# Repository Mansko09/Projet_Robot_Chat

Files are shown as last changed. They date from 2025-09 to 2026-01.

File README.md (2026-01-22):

# Projet Robot Chat

**ESE – Projet de groupe**

## Introduction

Dans le cadre de la spécialité de 3e année ESE à l'ENSEA, ce projet a pour objectif la conception complète d’un **robot mobile autonome à deux roues motrices**, destiné à participer à un jeu de type **chat et souris** face aux robots des autres groupes. Ce projet a été réalisé par Florian, David, Danilo et Mantou.
Au-delà de l’aspect ludique, ce projet mobilise des compétences variées en **électronique**, **mécanique** et **logiciel embarqué temps réel**, avec des contraintes fortes de sécurité (anti-chute), de réactivité et de robustesse matérielle.

Le robot, nommé **Félix**, doit être capable de se déplacer de manière autonome, de détecter son environnement, de réagir à des événements physiques (vide, chocs) et d’adapter dynamiquement son comportement.

---

## Objectifs fonctionnels

Pour atteindre ce comportement, plusieurs fonctions clés doivent être mises en place :

1. **Déplacement**

   * Roues + moteurs
   * Drivers de moteurs (PWM via timers)
   * Encodeurs (lecture via timers)

2. **Anti-chute**

   * Détection des bords avec capteur **ToF** (I²C)

3. **Détection des adversaires**

   * Capteur **LIDAR** pour repérer d’autres robots

4. **Détection de collisions**

   * Échange de rôles lors d’un choc (capteur **accéléromètre**)

5. **Communication**

   * Liaison **Bluetooth** (STM32WB55CEU6)

6. **Alimentation**

   * Batterie et gestion d’énergie (7.2 V → régulateurs 5 V & 3.3 V)

---

## Composants principaux

* **Microcontrôleur** : STM32WB55CEU6 (ARM Cortex-M4, BLE intégré)
* **Quartz** : 32 MHz 
* **Connecteur SWD/STLink** : (Farnell : 3226055)
* **Moteurs** : DFRobot FIT0520 ou FIT0521
* **Alimentation** : Batterie NiMH 7.2 V 1.3 Ah (RS : 777-0377)

  * Régulateur 5 V : MP1475DJ-LF-P
  * Régulateur 3.3 V : BU33SD5WG-TR
* **Drivers moteurs** : ZXBM5210 (un par roue)
* **Capteurs** :

  * LIDAR YDLIDAR X2
  * Accéléromètre ADXL343BCCZ-RL
  * Capteur ToF anti-chute
  * Multiplexeur : TCA9548A
* **Connecteurs** : JST 2.54 mm
* **Interface utilisateur** :

  * LED rouge/verte
  * Boutons poussoirs Wurth 430182070816 (6×6 mm, H9.5 mm)
  * Interrupteur ON/OFF Wurth 472121020311

---

## Conception réalisée

1. **Électronique**

   * Schéma électrique et PCB personnalisé
   * Routage, fabrication et soudure des composants

2. **Mécanique**

   * Conception du châssis sur **Onshape**
   * Intégration du PCB, moteurs, capteurs et batterie

3. **Logiciel embarqué**

   * Contrôle moteurs et capteurs

## Avancement du projet

* [x] Choix des composants et architecture générale
* [x] Schéma et routage PCB
* [x] Impression 3D du robot
* [x] Développement logiciel de base
* [ ] Intégration LIDAR et logique “chat/souris”

## Architecture générale 



## Structure du Code



### 1. Cerveau et Communication

Nous avons retenu le microcontrôleur **STM32WB55CEU6**, un choix motivé par des considérations de performance, de modularité et de fiabilité.

- **Mobilité et pilotage des drivers**  
  Chaque moteur est commandé par un driver piloté en PWM. Le logiciel intègre une gestion avancée des rampes de vitesse avec des profils asymétriques : accélération progressive et freinage brutal. Cette approche permet de préserver les moteurs tout en assurant un arrêt d’urgence immédiat lors de la détection de vide.  
  Les modes de freinage exploitent le **BRAKE_MODE** (court-circuit des moteurs) via le pont en H afin de garantir une immobilisation quasi instantanée sur les bords de table.

- **Intelligence embarquée et navigation**  
  Grâce à l’odométrie différentielle et aux encodeurs, la position $(x, y)$ ainsi que l’orientation $(\theta)$ du robot sont calculées en temps réel, permettant une navigation autonome précise.

- **Architecture logicielle sous FreeRTOS**  
  Le logiciel est structuré autour de plusieurs tâches concurrentes :
  - **Task_TOF** : mise à jour de la variable `vide` toutes les 20 ms, indiquant l’identifiant du capteur ToF détectant un vide ;
  - **Task_Motor** : gestion de l’odométrie et application des signaux PWM toutes les 10 ms ;
  - **Task_Control** : tâche décisionnelle principale, exécutée toutes les 20 ms, implémentant une machine à états finis (FSM) pilotant le comportement global du robot.

  **Rôle détaillé de la Task_Control**  
  La tâche **Task_Control** agit comme le véritable « cerveau » du robot. Elle fonctionne de manière asynchrone par rapport à la commande des moteurs et s’appuie sur une **Machine à États Finis (FSM)** pour orchestrer les actions de Félix en fonction des événements extérieurs.

  1. **Gestion de l’état global (Start / Stop)**  
     Avant toute logique de déplacement, la tâche surveille le flag `AccData`, mis à jour par l’accéléromètre via une interruption matérielle.  
     Un choc détecté agit comme un interrupteur logiciel (*toggle*) :
     - passage à l’état **Inactif** : LED rouge allumée, moteurs coupés ;
     - passage à l’état **Actif** : LED verte allumée, lancement de la mission.

  2. **Séquençage des déplacements (FSM)**  
     Lorsque le robot est actif, il suit un cycle comportemental conçu pour la survie et l’exploration :
     - **MOVE_FWD (marche avant)** : état par défaut. La tâche surveille en continu le registre `vide`. Dès qu’une bordure est détectée par un capteur ToF, une transition immédiate vers l’état de freinage est imposée.
     - **MOVE_BRAKE (sécurité)** : état intermédiaire déclenchant un arrêt d’urgence, voire une brève impulsion inverse, afin de compenser l’inertie et empêcher le dépassement du bord.
     - **MOVE_BACKWARD & MOVE_TURN** : une fois le robot immobilisé, une manœuvre de dégagement est engagée. Celle-ci est temporisée par `timer_state` et permet au robot de reculer, de modifier son orientation, puis de revenir automatiquement à l’état **MOVE_FWD**.

- **Perception sensorielle anti-chute**  
  Quatre capteurs **ToF VL53L0X** surveillent en permanence les angles du robot afin de détecter la présence de vide.

- **Détection de choc**  
  L’accéléromètre **ADXL343** est configuré en mode *Single Tap*. Un choc mécanique déclenche une interruption matérielle (EXTI) provoquant l’arrêt immédiat du robot et l’allumage de la LED rouge. Un second choc relance le système et active la LED verte.

## Ce qui fonctionne

- Déplacement fluide à une vitesse donnée du robot
- Détection de vide par les capteurs **ToF**
- Détection de choc par l’**accéléromètre**
- Gestion des LED d’état
- Changement de comportement en fonction :
  - de la détection de vide ;
  - de la détection de choc (Start / Stop)
 
## Ce qui ne fonctionne pas / partiellement

- **Bluetooth** : dysfonctionnement lié à un problème de quartz, empêchant la communication BLE
- **LIDAR** : matériel fonctionnel, mais logique logicielle incomplète
- **Asservissement** : implémenté mais non testé

## Challenges techniques rencontrés

### 1. Routage du PCB
Le premier défi a été le routage de la carte électronique :
- placement optimal des composants dans un espace réduit ;
- maintien des condensateurs de découplage au plus près du microcontrôleur ;
- isolation stricte de l’antenne Bluetooth ;
- optimisation des plans de masse ;
- éviter toute structure pouvant agir comme une antenne parasite.

### 2. Programmation du comportement du robot
Coder le comportement de Félix a été un défi majeur, non pas par la complexité de chaque fonction, mais par la nécessité de synchroniser une **logique** avec des **contraintes physiques réelles**.

#### a. Gestion du temps réel (priorités FreeRTOS)
Le robot ne doit jamais tomber, même lorsqu’il exécute d’autres calculs.
- **Problème** : la lecture des ToF via I²C est lente, alors que les moteurs nécessitent des mises à jour très fréquentes.
- **Solution** : architecture préemptive avec une priorité plus élevée pour la tâche ToF. En cas de détection de bord, elle interrompt la logique de contrôle pour forcer l’arrêt immédiat.

#### b. Passage du “tout ou rien” aux rampes (inertie)
- **Problème** : arrêts trop brutaux/lents provoquant des contraintes mécaniques (robot trop lourd à l'avant) ou un arrêt avec une roue en dehors de la table.
- **Solution** : implémentation de rampes asymétriques dans `Motor_UpdateSpeed` :
  - accélération douce (100 unités) ;
  - freinage très rapide (1000 unités).

Ce compromis entre protection mécanique et réactivité a nécessité de nombreux réglages.

#### c. Machine à États
- **Problème** : risque de blocage dans des situations critiques (coin de table, détections multiples).
- **Solution** : FSM rigoureuse avec des conditions de sortie strictes pour chaque état  
  (MOVE_FWD, MOVE_BRAKE, MOVE_BACKWARD, MOVE_TURN), garantissant un comportement déterministe et robuste.

https://github.com/user-attachments/assets/55dbaec2-2ef9-4583-8b24-4435a5f01540

## Conclusion

Ce projet a permis de mettre en pratique l’ensemble de la chaîne de conception d’un système embarqué autonome, depuis le routage d’un PCB jusqu’à la programmation temps réel sous FreeRTOS.  
Malgré certaines fonctionnalités incomplètes (Bluetooth, LIDAR), le robot démontre un comportement fiable et sécurisé face aux événements critiques. Les défis rencontrés ont été formateurs et ont mis en évidence l’importance de l’architecture logicielle et des choix matériels en amont dans un système embarqué réel.

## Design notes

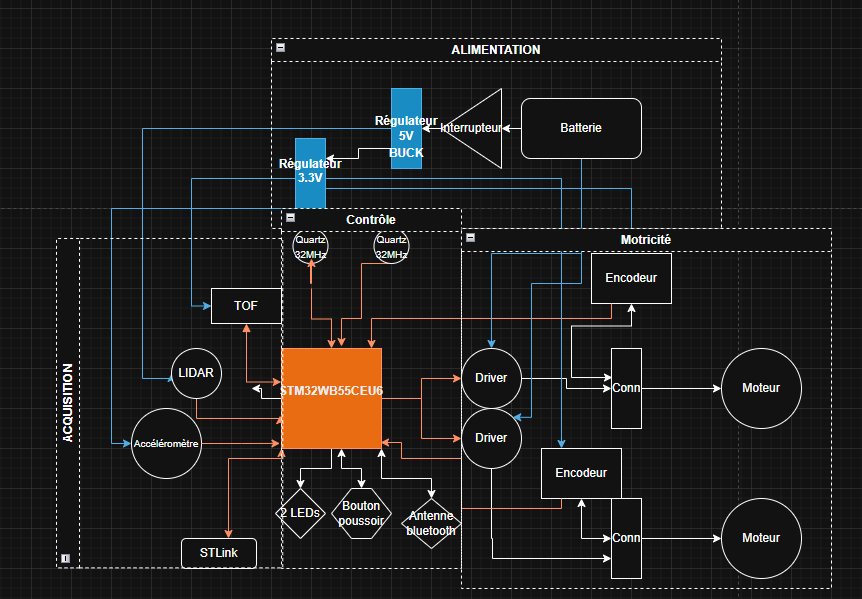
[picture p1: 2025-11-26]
Screenshots/Architecture_generale_Robot_Chat.png

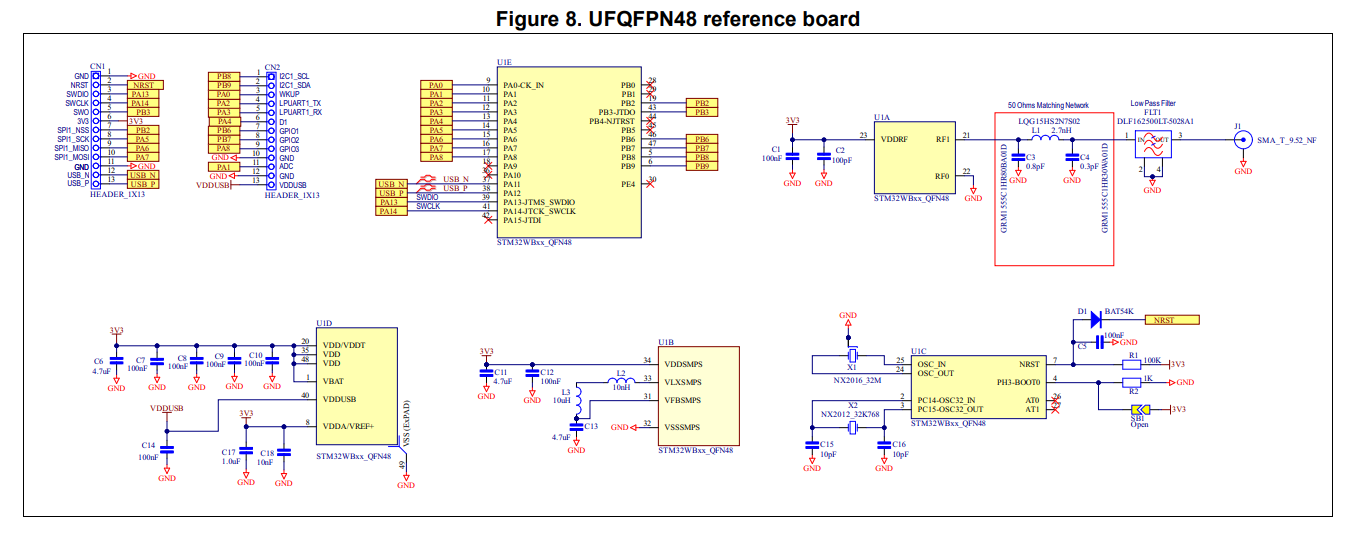
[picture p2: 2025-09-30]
Hardware/ROBOT-CHAT_PCB/Schematic_PCB/Capture d'écran 2025-09-11 083949.png

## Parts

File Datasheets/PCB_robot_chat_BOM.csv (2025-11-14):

Reference | Qty | Value | DNP | Exclude from BOM | Exclude from Board | Footprint | Datasheet
BU33SD5WG-TR1 | 1 | ~ |  |  |  | Package_TO_SOT_SMD:SOT-23-5
C1,C2,C11,C25,C27,C29 | 6 | 1uF |  |  |  | Capacitor_SMD:C_0603_1608Metric | ~
C3,C9,C15,C16 | 4 | 4.7uF |  |  |  | Capacitor_SMD:C_0603_1608Metric | ~
C4,C5,C6,C7,C8,C10,C13,C19,C20,C26,C28,C30 | 12 | 100n |  |  |  | Capacitor_SMD:C_0402_1005Metric | ~
C12 | 1 | 10nF |  |  |  | Capacitor_SMD:C_0402_1005Metric | ~
C14 | 1 | 100pF |  |  |  | Capacitor_SMD:C_0402_1005Metric | ~
C17,C18 | 2 | 10pF |  |  |  | Capacitor_SMD:C_0402_1005Metric | ~
C21 | 1 | 0.8pF |  |  |  | Capacitor_SMD:C_0402_1005Metric | ~
C22 | 1 | 22uF |  |  |  | Capacitor_SMD:C_0805_2012Metric | ~
C23,C301 | 2 | 22u |  |  |  | Capacitor_SMD:C_0805_2012Metric | ~
C24 | 1 | 0.3pF |  |  |  | Capacitor_SMD:C_0402_1005Metric | ~
D1 | 1 | LED |  |  |  | LED_SMD:LED_0603_1608Metric | ~
H101,H102,H103,H104 | 4 | MountingHole_Pad |  | Exclure de la Liste du Matériel |  | MountingHole:MountingHole_2.5mm_Pad_Via | ~
J1 | 1 | Conn_01x04 |  |  |  | Connector_JST:JST_XH_B4B-XH-AM_1x04_P2.50mm_Vertical | ~
J3,J4,J5,J6 | 4 | Conn_01x02 |  |  |  | Connector_JST:JST_PH_B2B-PH-K_1x02_P2.00mm_Vertical | ~
J7,J8 | 2 | Conn_01x06 |  |  |  | Connector_JST:JST_PH_B6B-PH-K_1x06_P2.00mm_Vertical | ~
J201 | 1 | Conn_ST_STDC14 |  |  |  | Connector_PinHeader_1.27mm:PinHeader_2x07_P1.27mm_Vertical_SMD | https://www.st.com/content/ccc/resource/technical/document/user_manual/group1/99/49/91/b6/b2/3a/46/e5/DM00526767/files/DM00526767.pdf/jcr:content/translations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
J501,J502,J503,J504 | 4 | Conn_01x04 |  |  |  | Connector_JST:JST_PH_B4B-PH-K_1x04_P2.00mm_Vertical | ~
L1 | 1 | 10nH |  |  |  | Inductor_SMD:L_0603_1608Metric | ~
L2 | 1 | 10uH |  |  |  | Inductor_SMD:L_0603_1608Metric | ~
L3 | 1 | 4.7uH |  |  |  | Bobine_74404054068:Bobine_74404054068 | ~
L4 | 1 | 2.7nH |  |  |  | Inductor_SMD:L_0603_1608Metric | ~
MP1475DJ-LF-P1 | 1 | ~ |  |  |  | Package_TO_SOT_SMD:TSOT-23-8
R1 | 1 | 16k |  |  |  | Resistor_SMD:R_0402_1005Metric | ~
R2 | 1 | 13k |  |  |  | Resistor_SMD:R_0402_1005Metric | ~
R3,R10 | 2 | 4.7k |  |  |  | Resistor_SMD:R_0402_1005Metric | ~
R4,R5,R6 | 3 | 1k |  |  |  | Resistor_SMD:R_0402_1005Metric | ~
R7,R301 | 2 | 100k |  |  |  | Resistor_SMD:R_0402_1005Metric | ~
R8 | 1 | 20 |  |  |  | Resistor_SMD:R_0402_1005Metric | ~
R9 | 1 | 40.2k |  |  |  | Resistor_SMD:R_0402_1005Metric | ~
R11,R12,R13,R14,R15,R16,R17,R18,R19,R20,R21 | 11 | 2k2 |  |  |  | Resistor_SMD:R_0402_1005Metric | ~
SW1 | 1 | SW_Push_Dual |  |  |  | SW_Push_1P1T_NO_6x6mm_H9.5mm:SW_Push_1P1T_NO_6x6mm_H9.5mm | ~
TP7,TP8,TP9,TP10,TP701,TP702,TP703,TP704 | 8 | TestPoint |  |  |  | TestPoint:TestPoint_Pad_D1.5mm | ~
U1 | 1 | STM32WB55CEUx |  |  |  | Package_DFN_QFN:QFN-48-1EP_7x7mm_P0.5mm_EP5.6x5.6mm | https://www.st.com/resource/en/datasheet/stm32wb55ce.pdf
U2 | 1 | TCA9546AD |  |  |  | Package_SO:SOIC-16_3.9x9.9mm_P1.27mm | https://www.ti.com/lit/ds/symlink/tca9546a.pdf
U4 | 1 | ADXL343 |  |  |  | Package_LGA:LGA-14_3x5mm_P0.8mm_LayoutBorder1x6y | https://www.analog.com/media/en/technical-documentation/data-sheets/ADXL343.pdf
U5,U6 | 2 | ZXBM5210-SP |  |  |  | Package_SO:Diodes_SO-8EP | https://www.diodes.com/assets/Datasheets/ZXBM5210.pdf
U7 | 1 | ~ |  |  |  | AMCA31-2R450G-S1F-T3:AMCA31-2R450G-S1F-T3
U8 | 1 | ~ |  |  |  | LowPass:LOWPASS
Y2 | 1 | 32MHz |  |  |  | XRCGB32M000F2P01R0:XRCGB32M000F2P01R0 | ~
Y201 | 1 | Crystal_Small |  |  |  | ABS07AIG-32.768KHZ-6-D-T:ABS07AIG-32.768KHZ-6-D-T | ~

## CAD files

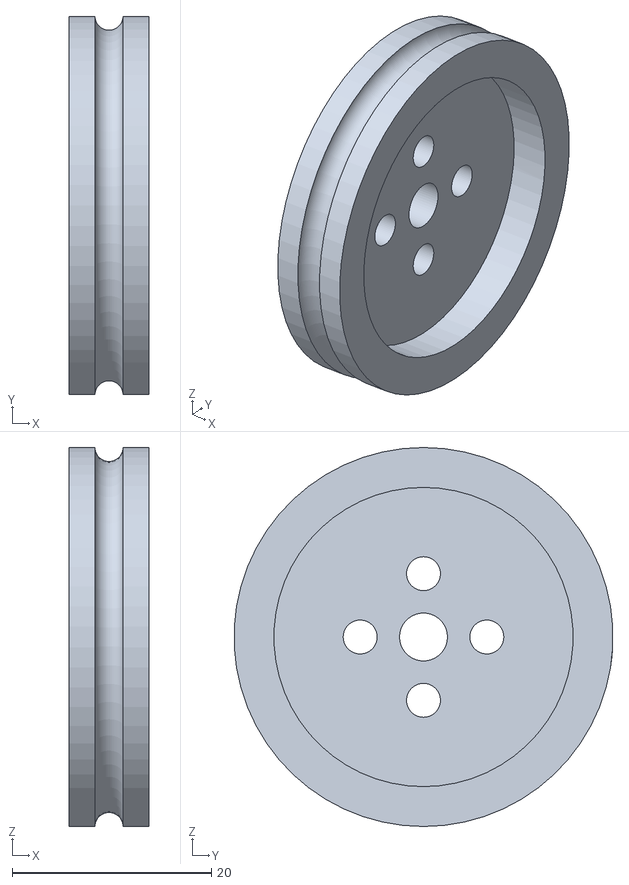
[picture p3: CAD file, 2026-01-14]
Meca/Wheels Clean V2.stl
8.00 x 37.9 x 38.0

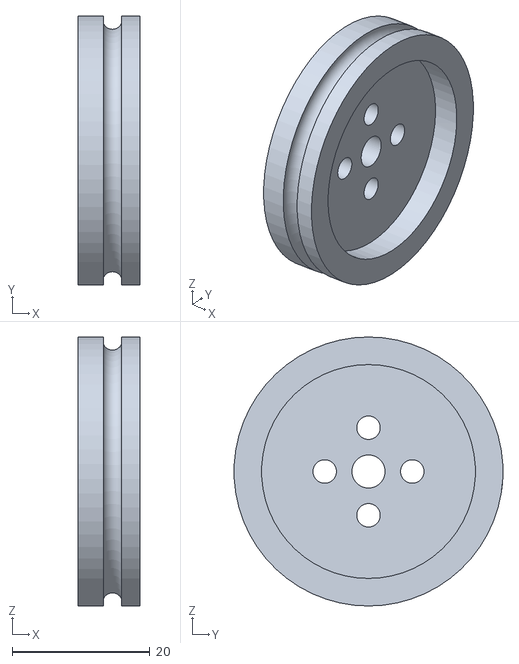
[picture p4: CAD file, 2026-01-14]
Meca/Wheels_Clean_V4.stl
9.00 x 38.9 x 39.0

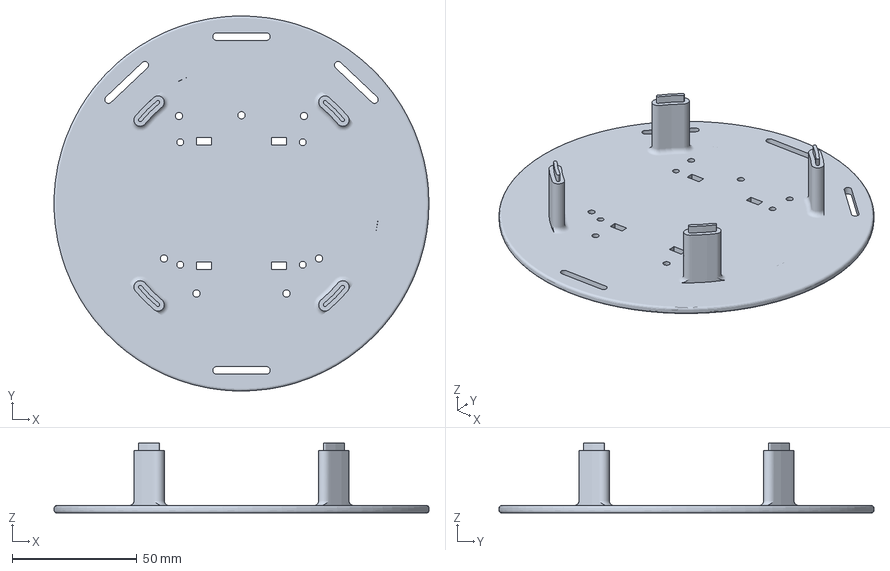
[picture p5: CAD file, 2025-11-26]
Meca/Tower - TOF.3mf
150.0 x 150.0 x 28.0 mm

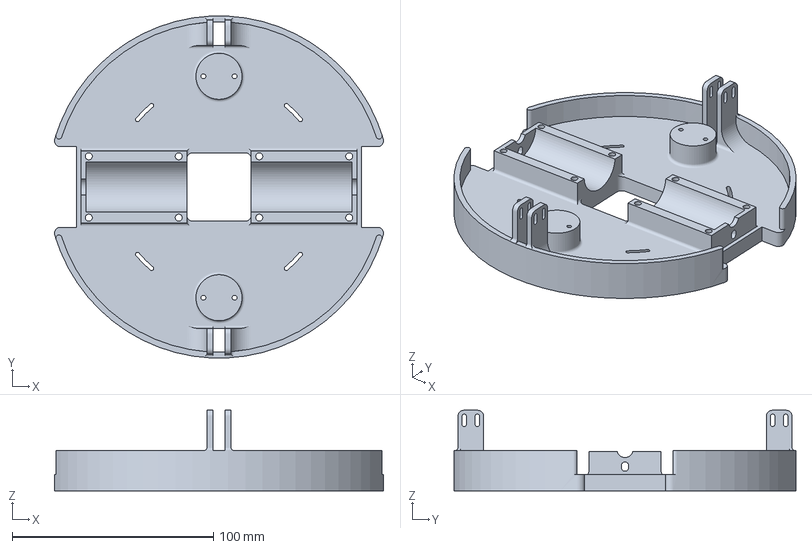
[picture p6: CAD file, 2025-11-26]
Meca/Base - Parts.3mf
163.4 x 169.8 x 40.0 mm

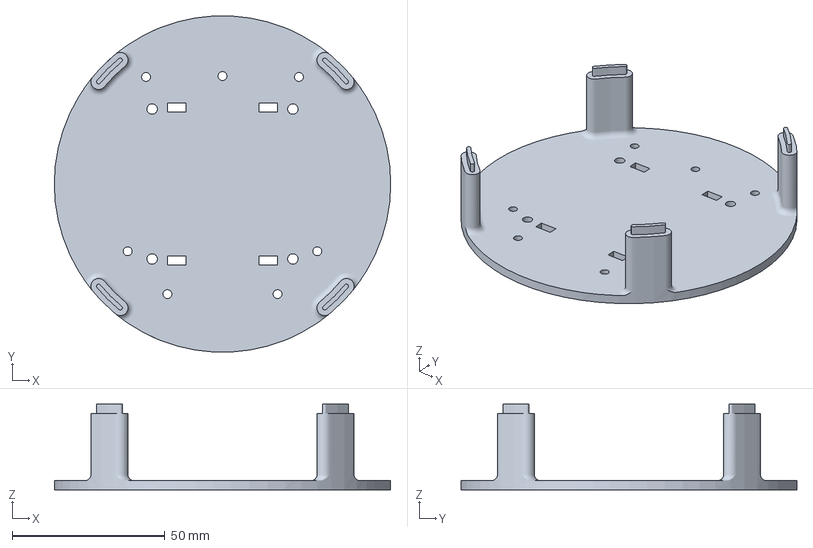
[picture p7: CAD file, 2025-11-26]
Meca/Tower - Parts.3mf
110.0 x 109.8 x 28.0 mm

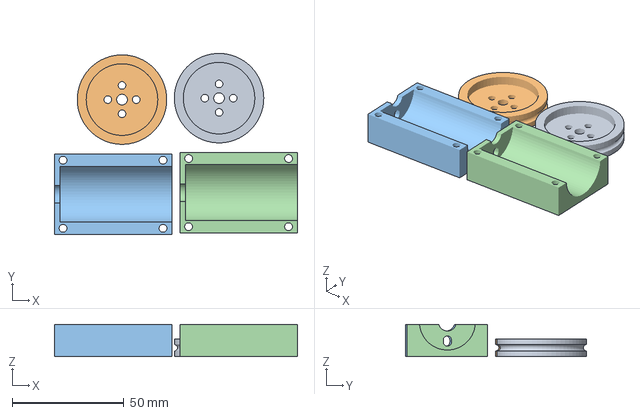
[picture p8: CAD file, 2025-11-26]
Meca/Wheels Clean.3mf
108.6 x 80.9 x 14.5 mm
Wheels Clean.stl x 2
Base - Parts - Support Motor.stl x 2

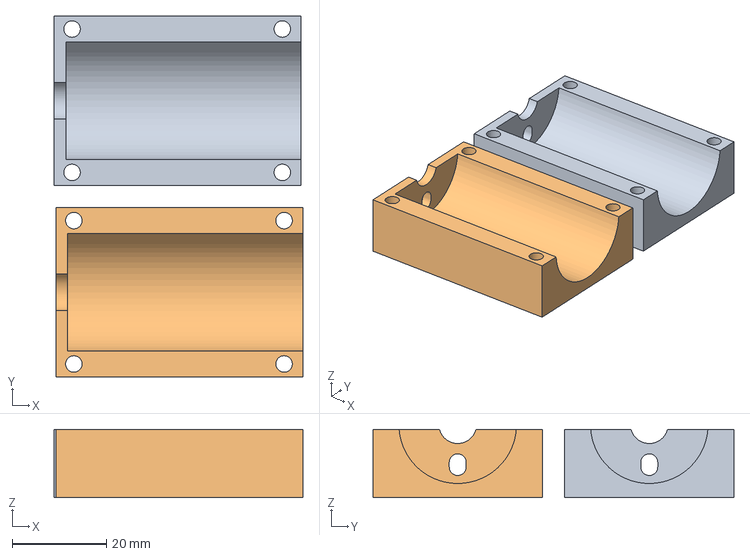
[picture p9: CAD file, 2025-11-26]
Meca/Base - Parts - Support Motor.3mf
52.9 x 76.7 x 14.5 mm
Base - Parts - Support Motor.stl x 2

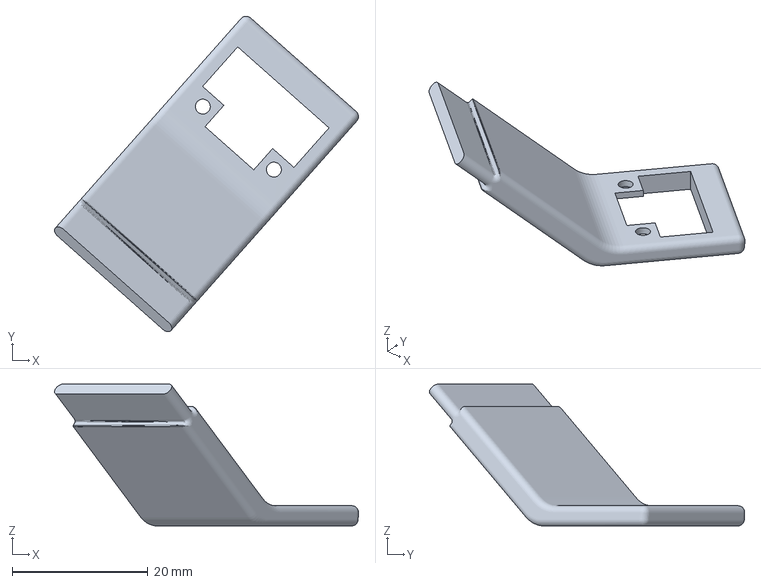
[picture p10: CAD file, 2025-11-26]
Meca/TOF.3mf
44.8 x 46.5 x 20.9 mm

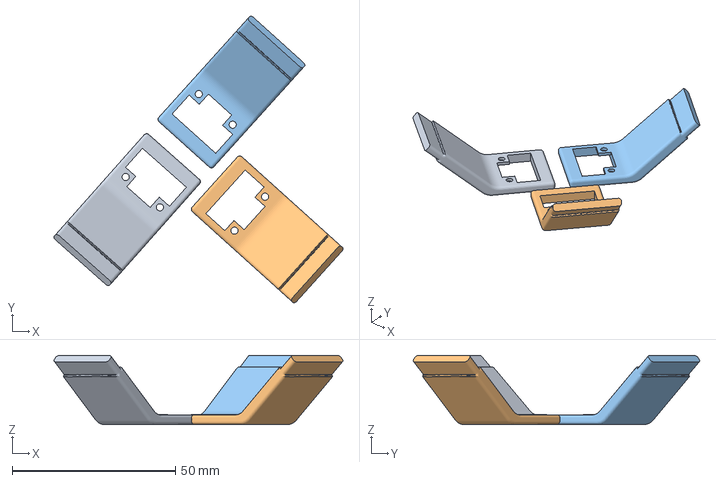
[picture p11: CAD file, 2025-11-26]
Meca/TOF_V3.3mf
88.6 x 87.8 x 21.2 mm
TOF_V3.stl x 3

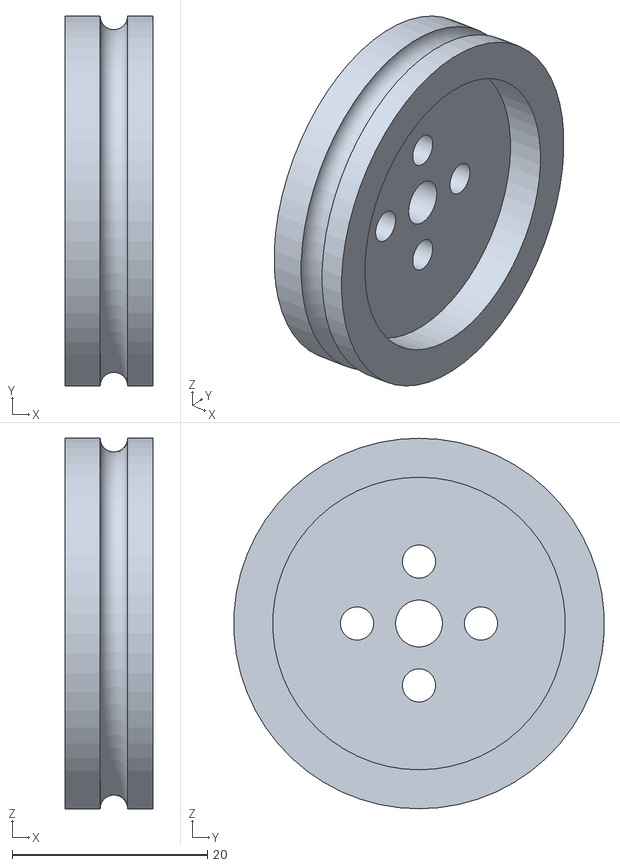
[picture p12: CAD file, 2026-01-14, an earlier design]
Meca/Wheels_Clean_V3.stl
9.00 x 37.9 x 38.0

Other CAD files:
Meca/TOF_V2.3mf
Meca/Base - Parts - Support Motor.stl
Meca/Base - Parts.stl
Meca/TOF.stl
Meca/TOF_V2.stl
Meca/TOF_V3.stl
Meca/Tower - Parts.stl
Meca/Tower - TOF.stl
Meca/Wheels Clean.stl

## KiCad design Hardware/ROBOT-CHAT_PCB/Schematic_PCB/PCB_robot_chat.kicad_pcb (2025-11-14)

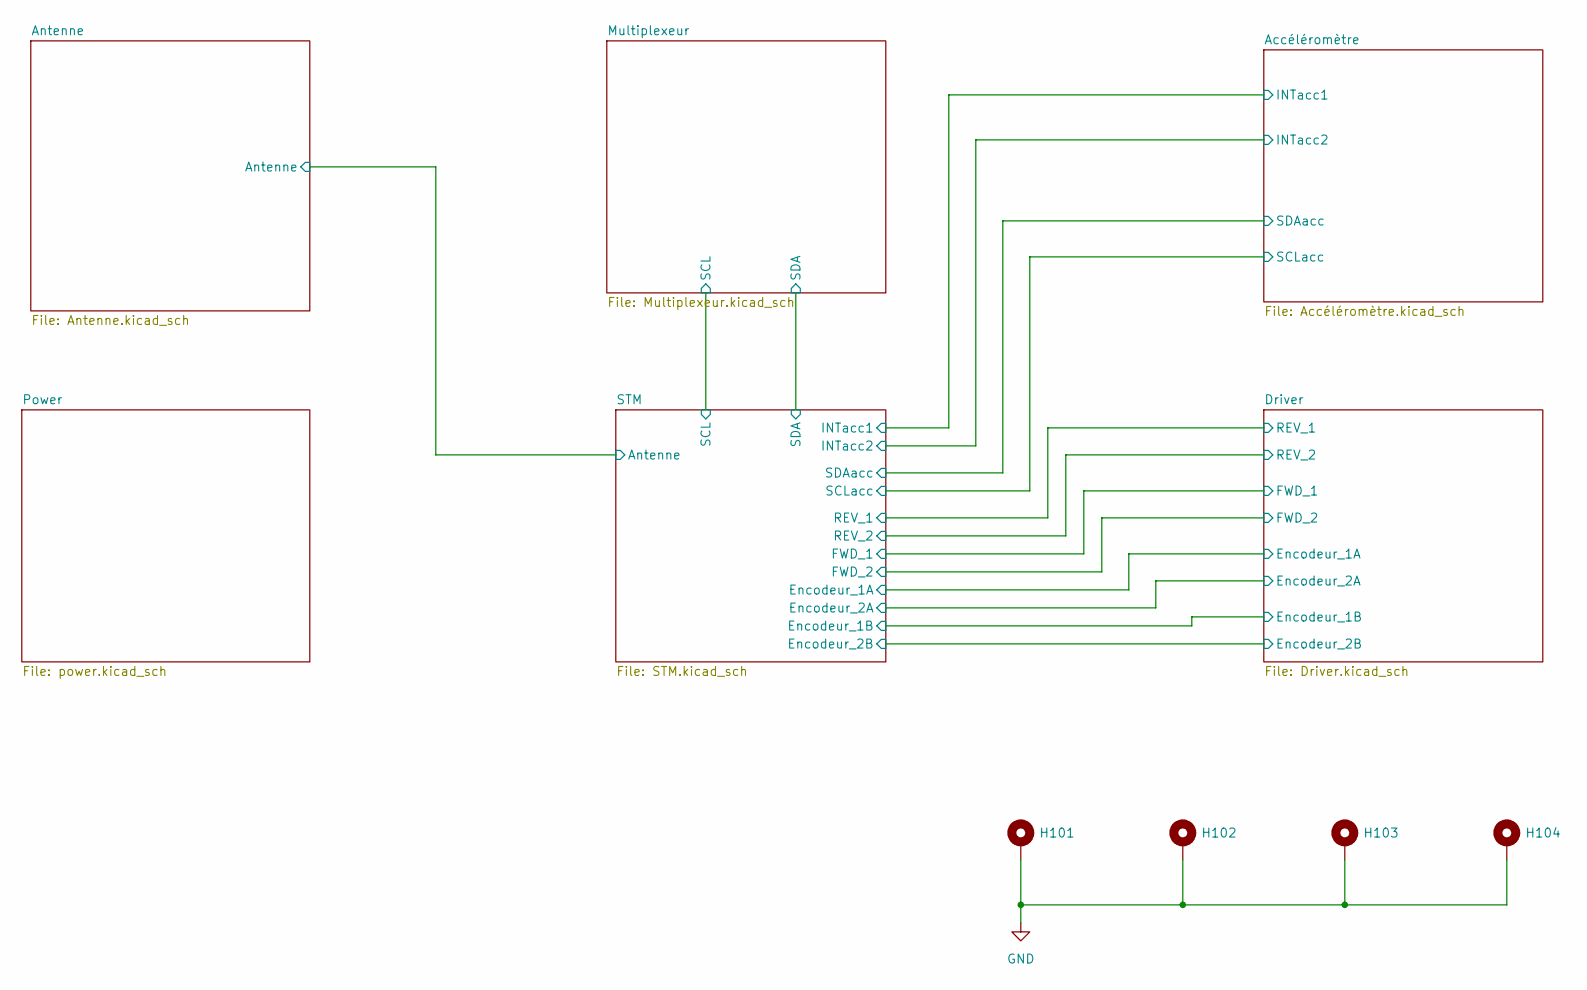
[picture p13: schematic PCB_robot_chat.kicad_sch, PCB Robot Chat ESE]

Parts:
H101, H102, H103, H104: MountingHole_Pad; MountingHole_2.5mm_Pad_Via

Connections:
GND: H101.1, H102.1, H103.1, H104.1; also elsewhere on the board

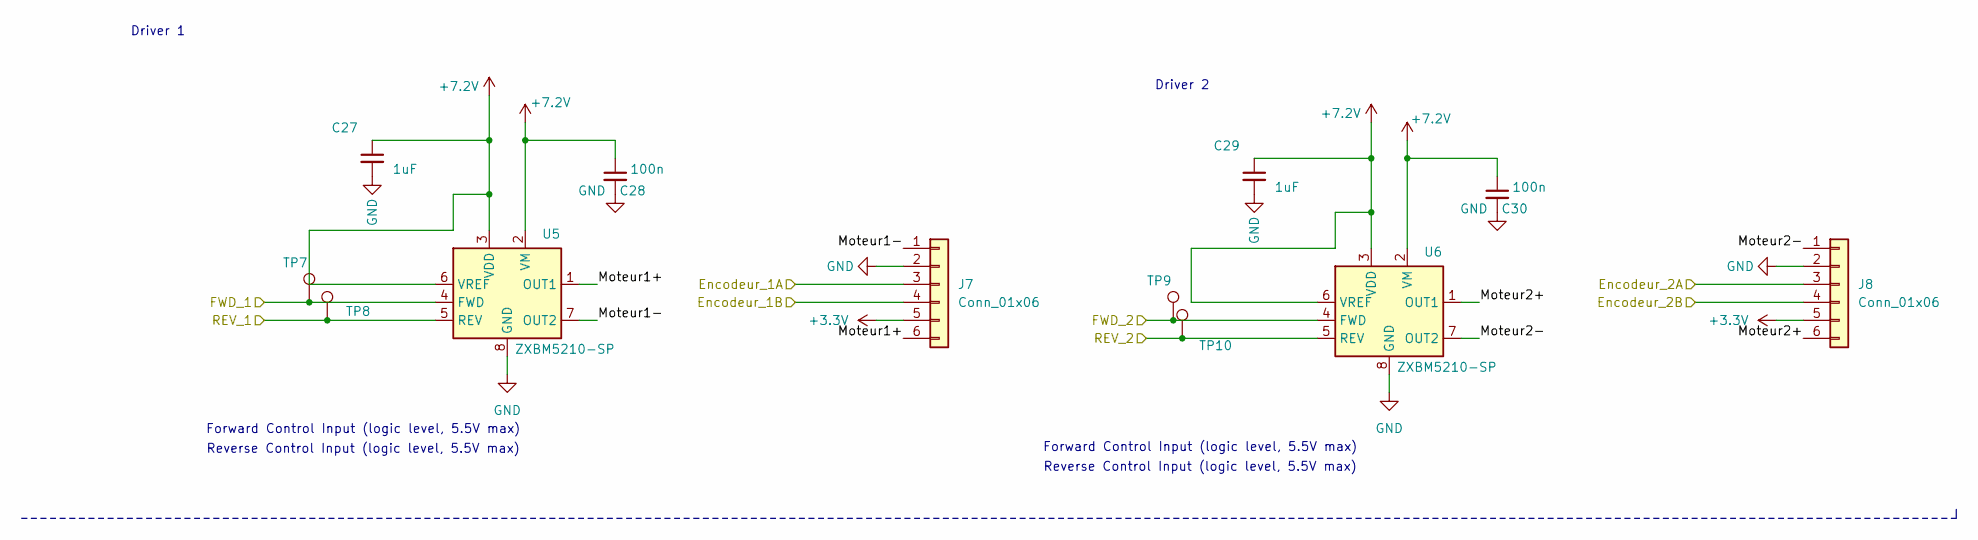
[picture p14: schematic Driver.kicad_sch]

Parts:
C27, C29: 1uF; C_0603_1608Metric
C28, C30: 100n; C_0402_1005Metric
J7, J8: Conn_01x06; JST_PH_B6B-PH-K_1x06_P2.00mm_Vertical
TP7, TP8, TP9, TP10: TestPoint; TestPoint_Pad_D1.5mm
U5, U6: ZXBM5210-SP; Diodes_SO-8EP

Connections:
+3.3V: J7.5, J8.5; also elsewhere on the board
+7.2V: C27.1, C28.1, C29.1, C30.1, U5.2 (VM), U5.3 (VDD), U5.6 (VREF), U6.2 (VM), U6.3 (VDD), U6.6 (VREF); also elsewhere on the board
/Driver/Encodeur_1A: J7.3; also elsewhere on the board
/Driver/Encodeur_1B: J7.4; also elsewhere on the board
/Driver/Encodeur_2A: J8.3; also elsewhere on the board
/Driver/Encodeur_2B: J8.4; also elsewhere on the board
/Driver/FWD_1: TP7.1, U5.4 (FWD); also elsewhere on the board
/Driver/FWD_2: TP9.1, U6.4 (FWD); also elsewhere on the board
/Driver/Moteur1+: J7.6, U5.1 (OUT1)
/Driver/Moteur1-: J7.1, U5.7 (OUT2)
/Driver/Moteur2+: J8.6, U6.1 (OUT1)
/Driver/Moteur2-: J8.1, U6.7 (OUT2)
/Driver/REV_1: TP8.1, U5.5 (REV); also elsewhere on the board
/Driver/REV_2: TP10.1, U6.5 (REV); also elsewhere on the board
GND: C27.2, C28.2, C29.2, C30.2, J7.2, J8.2, U5.8 (GND), U5.9 (GND), U6.8 (GND), U6.9 (GND); also elsewhere on the board

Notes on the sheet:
Forward Control Input (logic level, 5.5V max)
Driver 2
Reverse Control Input (logic level, 5.5V max)
Driver 1

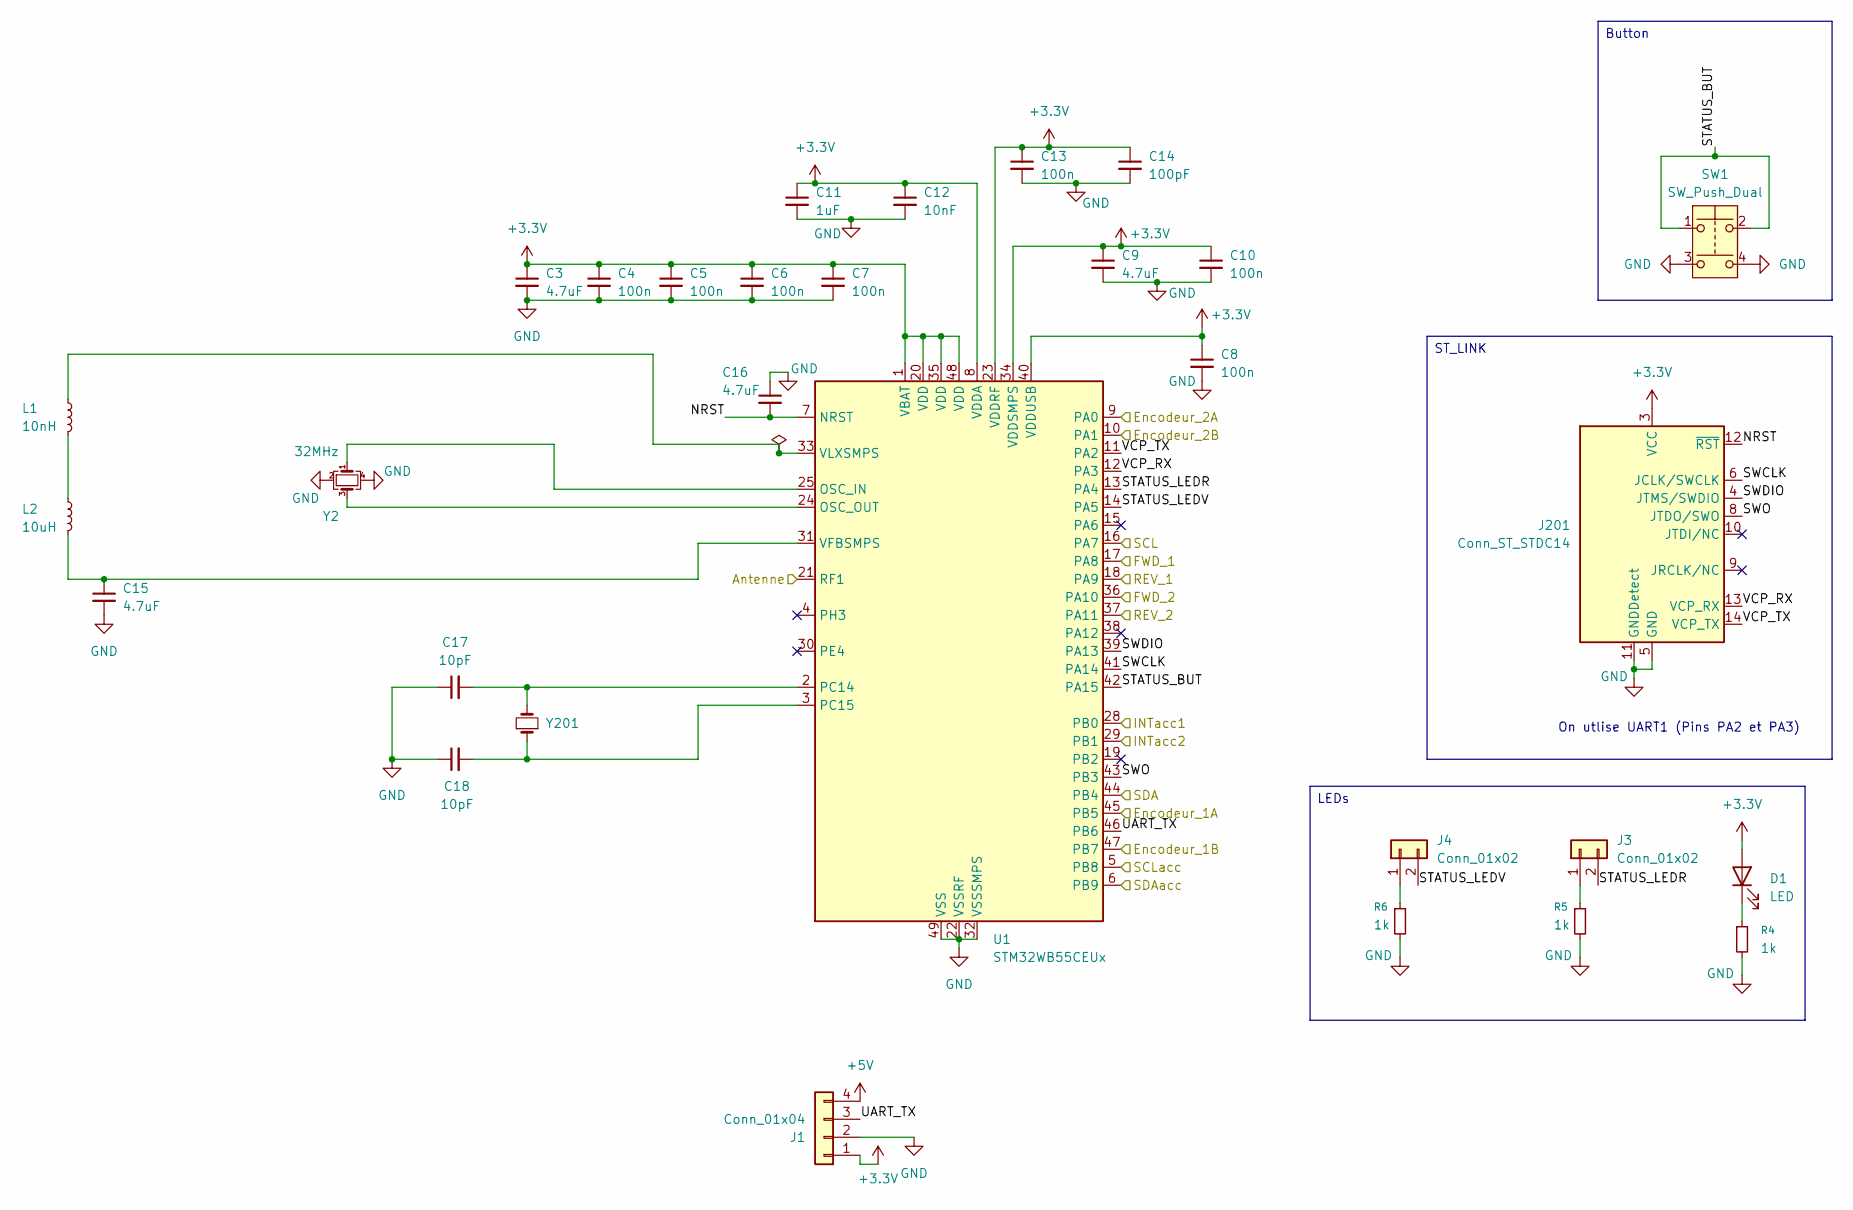
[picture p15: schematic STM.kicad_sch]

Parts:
C3, C9, C15, C16: 4.7uF; C_0603_1608Metric
C4, C5, C6, C7, C8, C10, C13: 100n; C_0402_1005Metric
C11: 1uF; C_0603_1608Metric
C12: 10nF; C_0402_1005Metric
C14: 100pF; C_0402_1005Metric
C17, C18: 10pF; C_0402_1005Metric
D1: LED; LED_0603_1608Metric
J1: Conn_01x04; JST_XH_B4B-XH-AM_1x04_P2.50mm_Vertical
J3, J4: Conn_01x02; JST_PH_B2B-PH-K_1x02_P2.00mm_Vertical
J201: Conn_ST_STDC14; PinHeader_2x07_P1.27mm_Vertical_SMD
L1: 10nH; L_0603_1608Metric
L2: 10uH; L_0603_1608Metric
R4, R5, R6: 1k; R_0402_1005Metric
SW1: SW_Push_Dual; SW_Push_1P1T_NO_6x6mm_H9.5mm
U1: STM32WB55CEUx; QFN-48-1EP_7x7mm_P0.5mm_EP5.6x5.6mm
Y2: 32MHz; XRCGB32M000F2P01R0
Y201: Crystal_Small; ABS07AIG-32.768KHZ-6-D-T

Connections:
+3.3V: C3.1, C4.1, C5.1, C6.1, C7.1, C8.1, C9.1, C10.1, C11.1, C12.1, C13.1, C14.1, D1.2 (A), J1.1, J201.3 (VCC), U1.1 (VBAT), U1.8 (VDDA), U1.20 (VDD), U1.23 (VDDRF), U1.34 (VDDSMPS), U1.35 (VDD), U1.40 (VDDUSB), U1.48 (VDD); also elsewhere on the board
+5V: J1.4; also elsewhere on the board
/Accéléromètre/INTacc1: U1.28 (PB0); also elsewhere on the board
/Accéléromètre/INTacc2: U1.29 (PB1); also elsewhere on the board
/Accéléromètre/SCLacc: U1.5 (PB8); also elsewhere on the board
/Accéléromètre/SDAacc: U1.6 (PB9); also elsewhere on the board
/Antenne/Antenne: U1.21 (RF1); also elsewhere on the board
/Driver/Encodeur_1A: U1.45 (PB5); also elsewhere on the board
/Driver/Encodeur_1B: U1.47 (PB7); also elsewhere on the board
/Driver/Encodeur_2A: U1.9 (PA0); also elsewhere on the board
/Driver/Encodeur_2B: U1.10 (PA1); also elsewhere on the board
/Driver/FWD_1: U1.17 (PA8); also elsewhere on the board
/Driver/FWD_2: U1.36 (PA10); also elsewhere on the board
/Driver/REV_1: U1.18 (PA9); also elsewhere on the board
/Driver/REV_2: U1.37 (PA11); also elsewhere on the board
/Multiplexeur/SCL: U1.16 (PA7); also elsewhere on the board
/Multiplexeur/SDA: U1.44 (PB4); also elsewhere on the board
/STM/NRST: C16.2, J201.12 (~RST), U1.7 (NRST)
/STM/STATUS_BUT: SW1.1, SW1.2, U1.42 (PA15)
/STM/STATUS_LEDR: J3.2, U1.13 (PA4)
/STM/STATUS_LEDV: J4.2, U1.14 (PA5)
/STM/SWCLK: J201.6 (JCLK/SWCLK), U1.41 (PA14)
/STM/SWDIO: J201.4 (JTMS/SWDIO), U1.39 (PA13)
/STM/SWO: J201.8 (JTDO/SWO), U1.43 (PB3)
/STM/UART_TX: J1.3, U1.46 (PB6)
/STM/VCP_RX: J201.13 (VCP_RX), U1.12 (PA3)
/STM/VCP_TX: J201.14 (VCP_TX), U1.11 (PA2)
GND: C3.2, C4.2, C5.2, C6.2, C7.2, C8.2, C9.2, C10.2, C11.2, C12.2, C13.2, C14.2, C15.2, C16.1, C17.1, C18.1, J1.2, J201.5 (GND), J201.7 (GND), J201.11 (GNDDetect), R4.2, R5.2, R6.2, SW1.3, SW1.4, U1.22 (VSSRF), U1.32 (VSSSMPS), U1.49 (VSS), Y2.2, Y2.4; also elsewhere on the board
unnamed: D1.1 (K), R4.1
unnamed: J3.1, R5.1
unnamed: J4.1, R6.1
unnamed: L1.2, L2.1
unnamed: U1.25 (OSC_IN), Y2.1
unnamed: U1.24 (OSC_OUT), Y2.3
unnamed: C17.2, U1.2 (PC14), Y201.2
unnamed: C18.2, U1.3 (PC15), Y201.1
unnamed: C15.1, L2.2, U1.31 (VFBSMPS)
unnamed: L1.1, U1.33 (VLXSMPS)

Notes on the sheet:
On utlise UART1 (Pins PA2 et PA3)
Button
ST_LINK
LEDs

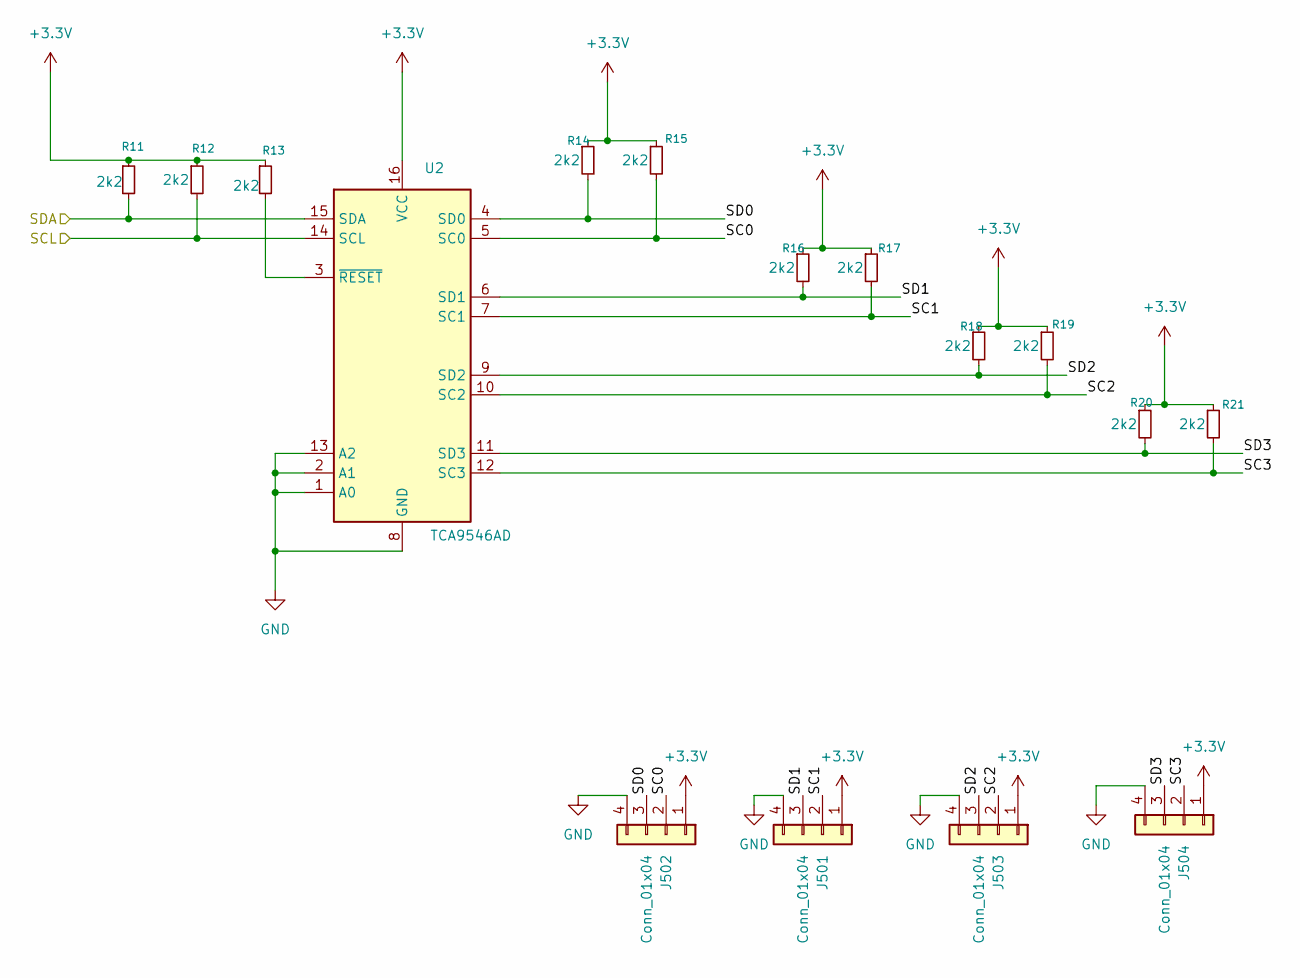
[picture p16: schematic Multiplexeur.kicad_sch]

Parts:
J501, J502, J503, J504: Conn_01x04; JST_PH_B4B-PH-K_1x04_P2.00mm_Vertical
R11, R12, R13, R14, R15, R16, R17, R18, R19, R20, R21: 2k2; R_0402_1005Metric
U2: TCA9546AD; SOIC-16_3.9x9.9mm_P1.27mm

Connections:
+3.3V: J501.1, J502.1, J503.1, J504.1, R11.1, R12.1, R13.1, R14.1, R15.1, R16.1, R17.1, R18.1, R19.1, R20.1, R21.1, U2.16 (VCC); also elsewhere on the board
/Multiplexeur/SC0: J502.2, R15.2, U2.5 (SC0)
/Multiplexeur/SC1: J501.2, R17.2, U2.7 (SC1)
/Multiplexeur/SC2: J503.2, R19.2, U2.10 (SC2)
/Multiplexeur/SC3: J504.2, R21.2, U2.12 (SC3)
/Multiplexeur/SCL: R12.2, U2.14 (SCL); also elsewhere on the board
/Multiplexeur/SD0: J502.3, R14.2, U2.4 (SD0)
/Multiplexeur/SD1: J501.3, R16.2, U2.6 (SD1)
/Multiplexeur/SD2: J503.3, R18.2, U2.9 (SD2)
/Multiplexeur/SD3: J504.3, R20.2, U2.11 (SD3)
/Multiplexeur/SDA: R11.2, U2.15 (SDA); also elsewhere on the board
GND: J501.4, J502.4, J503.4, J504.4, U2.1 (A0), U2.2 (A1), U2.8 (GND), U2.13 (A2); also elsewhere on the board
unnamed: R13.2, U2.3 (~RESET)

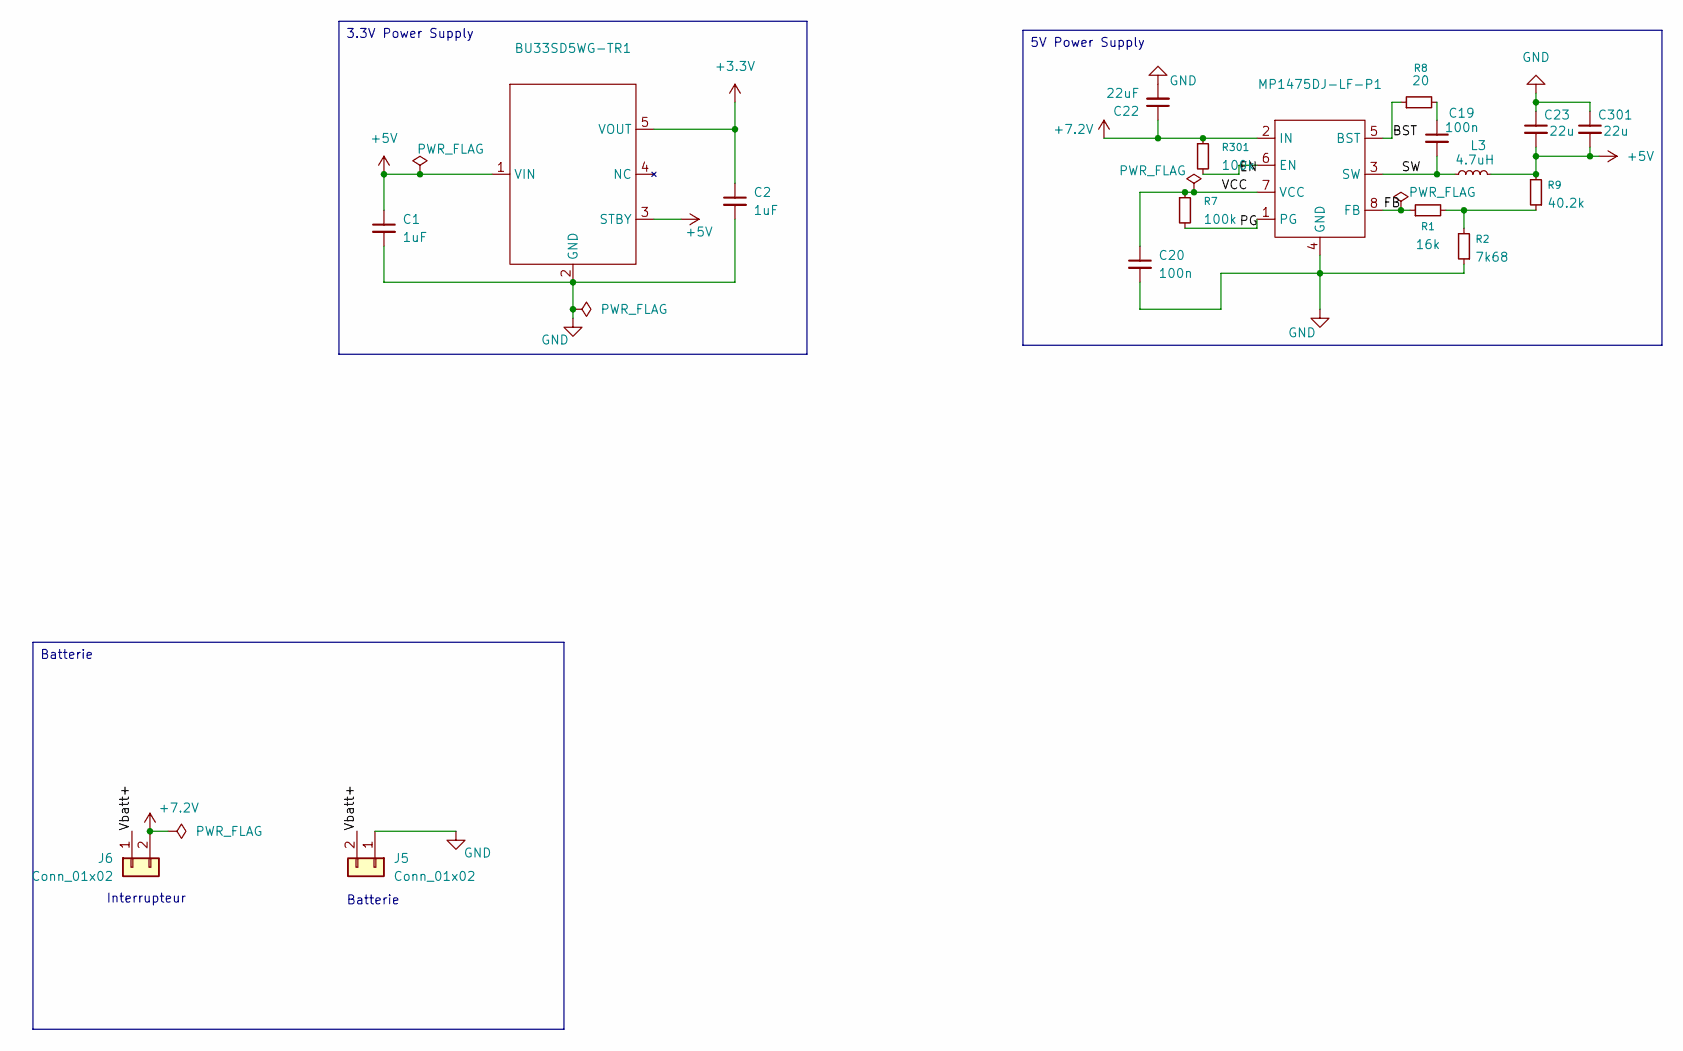
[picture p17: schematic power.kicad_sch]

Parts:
BU33SD5WG-TR1: SOT-23-5
C1, C2: 1uF; C_0603_1608Metric
C19, C20: 100n; C_0402_1005Metric
C22: 22uF; C_0805_2012Metric
C23, C301: 22u; C_0805_2012Metric
J5, J6: Conn_01x02; JST_PH_B2B-PH-K_1x02_P2.00mm_Vertical
L3: 4.7uH; Bobine_74404054068
MP1475DJ-LF-P1: TSOT-23-8
R1: 16k; R_0402_1005Metric
R2: 7k68; R_0402_1005Metric
R7, R301: 100k; R_0402_1005Metric
R8: 20; R_0402_1005Metric
R9: 40.2k; R_0402_1005Metric

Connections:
+3.3V: BU33SD5WG-TR1.5 (VOUT), C2.1; also elsewhere on the board
+5V: BU33SD5WG-TR1.1 (VIN), BU33SD5WG-TR1.3 (STBY), C1.1, C23.2, C301.2, L3.2, R9.2; also elsewhere on the board
+7.2V: C22.1, J6.2, MP1475DJ-LF-P1.2 (IN), R301.1; also elsewhere on the board
/Power/BST: MP1475DJ-LF-P1.5 (BST), R8.1
/Power/EN: MP1475DJ-LF-P1.6 (EN), R301.2
/Power/FB: MP1475DJ-LF-P1.8 (FB), R1.1
/Power/PG: MP1475DJ-LF-P1.1 (PG), R7.2
/Power/SW: C19.2, L3.1, MP1475DJ-LF-P1.3 (SW)
/Power/VCC: C20.1, MP1475DJ-LF-P1.7 (VCC), R7.1
/Power/Vbatt+: J5.2, J6.1
GND: BU33SD5WG-TR1.2 (GND), C1.2, C2.2, C20.2, C22.2, C23.1, C301.1, J5.1, MP1475DJ-LF-P1.4 (GND), R2.1; also elsewhere on the board
unnamed: C19.1, R8.2
unnamed: R1.2, R2.2, R9.1

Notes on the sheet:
Batterie
Interrupteur
3.3V Power Supply
5V Power Supply

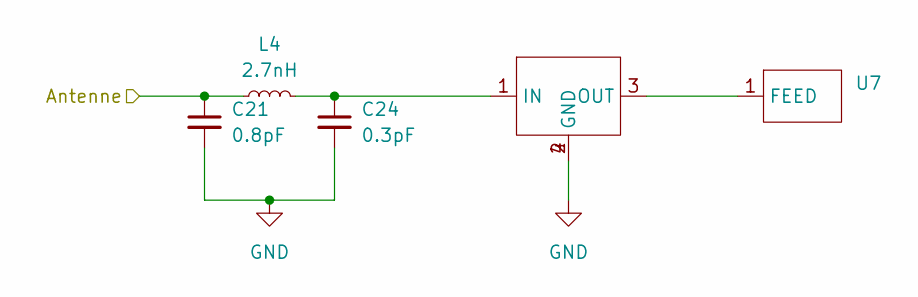
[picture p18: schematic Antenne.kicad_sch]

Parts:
C21: 0.8pF; C_0402_1005Metric
C24: 0.3pF; C_0402_1005Metric
L4: 2.7nH; L_0603_1608Metric
U7: AMCA31-2R450G-S1F-T3
U8: LOWPASS

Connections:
/Antenne/Antenne: C21.1, L4.1; also elsewhere on the board
GND: C21.2, C24.2, U8.2 (GND), U8.4 (GND); also elsewhere on the board
unnamed: U7.1 (FEED), U8.3 (OUT)
unnamed: C24.1, L4.2, U8.1 (IN)

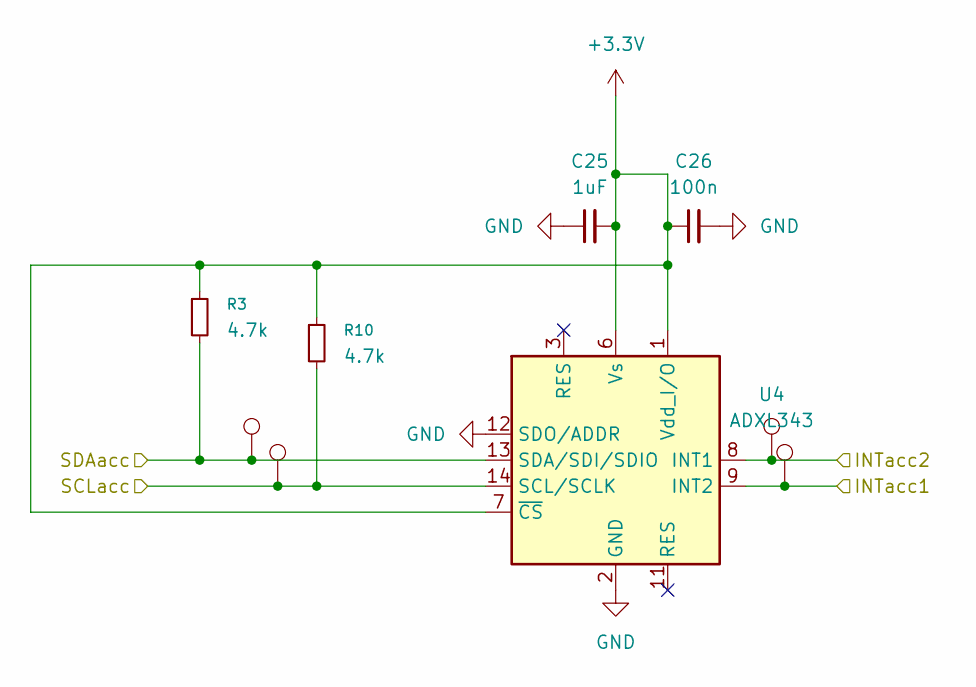
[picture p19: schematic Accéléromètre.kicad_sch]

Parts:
C25: 1uF; C_0603_1608Metric
C26: 100n; C_0402_1005Metric
R3, R10: 4.7k; R_0402_1005Metric
TP701, TP702, TP703, TP704: TestPoint; TestPoint_Pad_D1.5mm
U4: ADXL343; LGA-14_3x5mm_P0.8mm_LayoutBorder1x6y

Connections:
+3.3V: C25.2, C26.1, R3.1, R10.1, U4.1 (Vdd_I/O), U4.6 (Vs), U4.7 (~CS); also elsewhere on the board
/Accéléromètre/INTacc1: TP704.1, U4.9 (INT2); also elsewhere on the board
/Accéléromètre/INTacc2: TP703.1, U4.8 (INT1); also elsewhere on the board
/Accéléromètre/SCLacc: R10.2, TP702.1, U4.14 (SCL/SCLK); also elsewhere on the board
/Accéléromètre/SDAacc: R3.2, TP701.1, U4.13 (SDA/SDI/SDIO); also elsewhere on the board
GND: C25.1, C26.2, U4.2 (GND), U4.4 (GND), U4.5 (GND), U4.12 (SDO/ADDR); also elsewhere on the board

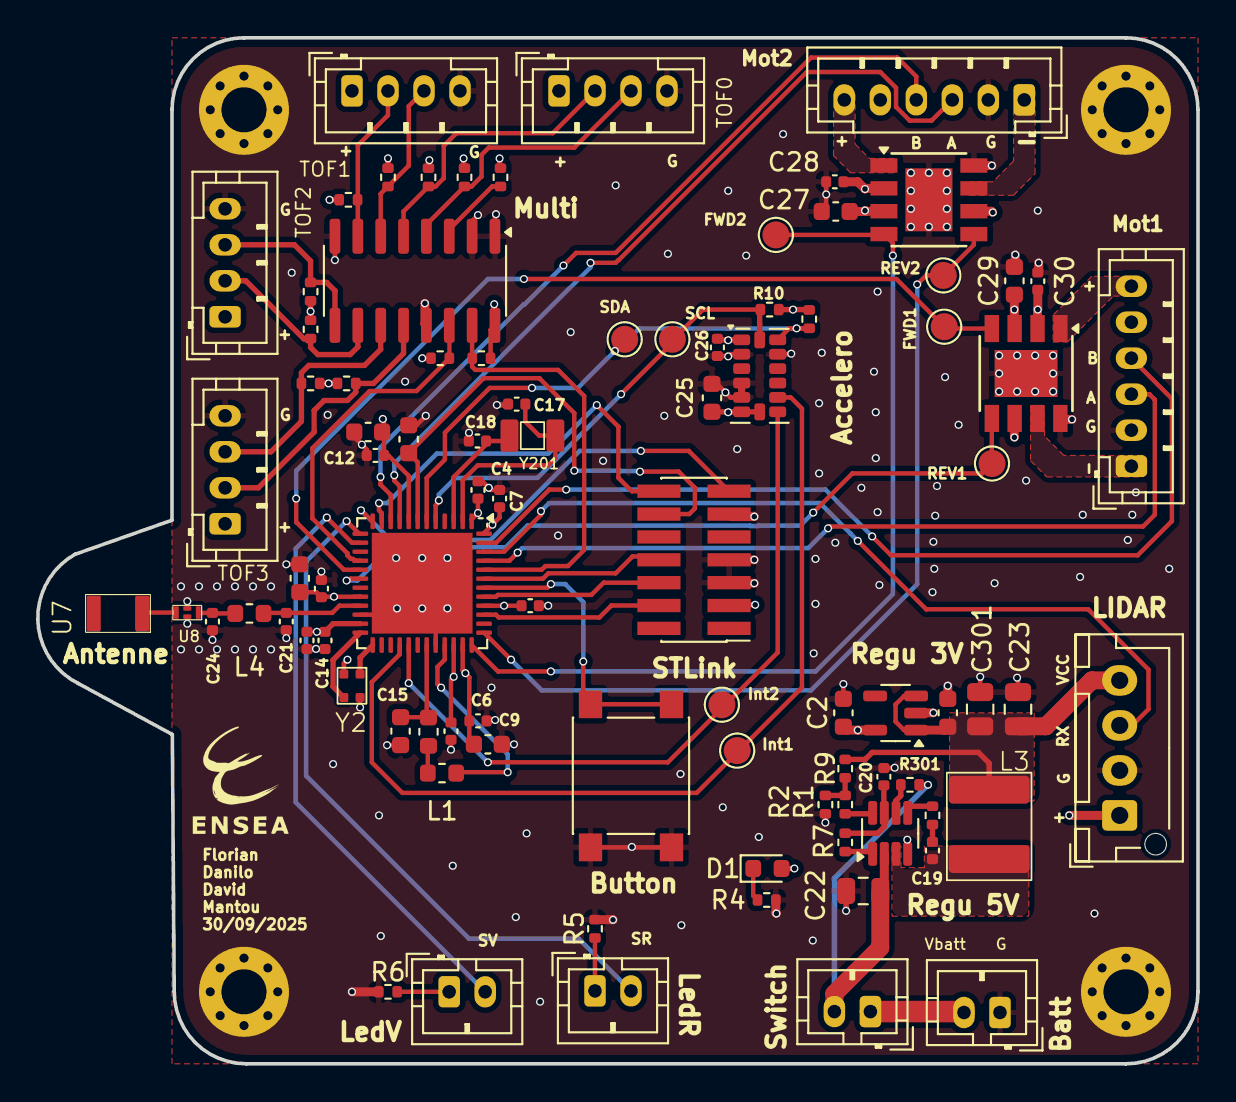
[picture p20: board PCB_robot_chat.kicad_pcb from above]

Board: 4 copper layers, 64.5 x 57.0 mm, 94 parts (0 on the bottom side), 63 nets.

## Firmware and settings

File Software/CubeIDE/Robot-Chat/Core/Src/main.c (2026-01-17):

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
/* Includes ------------------------------------------------------------------*/
#include "main.h"
#include "cmsis_os.h"
#include "i2c.h"
#include "lptim.h"
#include "usart.h"
#include "tim.h"
#include "gpio.h"

/* USER CODE BEGIN Includes */
#include <string.h>
#include <stdlib.h>
#include <math.h>
#include <stdio.h>
#include "../drivers/control.h"
#include "semphr.h"

/* USER CODE END Includes */

/* USER CODE BEGIN PD */
#define STACK_SIZE_SMALL   256
#define STACK_SIZE_MEDIUM  384

#define PRIO_CTRL    4
#define PRIO_TOF     3
#define PRIO_ODOM_MOTOR 5
#define PRIO_ACCEL   1
#define PRIO_LIDAR 2

#define TOF_TRESHHOLD 40


/* USER CODE END PD */


/* USER CODE BEGIN PV */
h_Motor_t hMotors;
Odom_t odom;
Encodeur_t enc;
PID_t pid_left;
PID_t pid_right;

h_control_t hControl;
//FREERTOS
SemaphoreHandle_t sem_TimerTOF;
SemaphoreHandle_t sem_ADXL;

//task handles
TaskHandle_t xTaskControlHandle = NULL;
TaskHandle_t xTaskToFHandle = NULL;
TaskHandle_t xTaskOdomMotorHandle = NULL;
TaskHandle_t xTaskTestHandle=NULL;
TaskHandle_t TaskTestOdomPollingHandle=NULL;


Odom_Params_t odom_params = {
		.wheel_radius = 0.02f,    // 4 cm de diametre donc 2 de rayon
		.wheel_base   = 0.153f,    // 15 cm entre roues
		.ticks_per_rev =  222.4f // cf datasheet moteurs
};

ADXL_InitTypeDef adxl ={
		.IntMode = INT_ACTIVEHIGH,
		.LPMode = LPMODE_NORMAL,
		.Rate = BWRATE_100,
		.Range = RANGE_4G,
		.Resolution = RESOLUTION_10BIT,
		.Justify = JUSTIFY_SIGNED,
		.AutoSleep = AUTOSLEEPOFF,
		.LinkMode = LINKMODEOFF
};


extern i2c_mux_t mux;

/* USER CODE END PV */

void SystemClock_Config(void);
void PeriphCommonClock_Config(void);
void MX_FREERTOS_Init(void);
/* USER CODE BEGIN 0 */
int __io_putchar(int ch)
{
	HAL_UART_Transmit(&hlpuart1, (uint8_t*)&ch, 1, HAL_MAX_DELAY);
	return ch;
}

static void ControlData_Init(void)
{
	hControl.AccData = 0;
	hControl.vide    = 0;
}


/* ============================= */
/*       TASK   ACCELERO          */
/* ============================= */

void HAL_GPIO_EXTI_Callback(uint16_t GPIO_Pin)
{
	if (GPIO_Pin == GPIO_PIN_0 || GPIO_Pin == GPIO_PIN_1){
		ADXL_IntProto();
		int16_t acc[3] = {0,0,0};
		ADXL_getAccel(acc ,OUTPUT_SIGNED);
		//printf("x : %d, y : %d, z : %d\r\n",(int)acc[0],(int)acc[1],(int)acc[2]);
		ADXL_disableSingleTap();
		BaseType_t higher_priority_task_woken = pdFALSE;
		xSemaphoreGiveFromISR(sem_ADXL, &higher_priority_task_woken);
		portYIELD_FROM_ISR(higher_priority_task_woken);
	}
}

void taskAccelDetection(void * unused){
	printf("[ACC] Start \r\n");
	uint8_t mesured_axes = X_axes | Y_axes;
	uint8_t duration_choc =0x1B;
	uint8_t threshold_choc = 0x21;

	for (;;){
		ADXL_enableSingleTap(INT2, mesured_axes,duration_choc, threshold_choc);
		xSemaphoreTake(sem_ADXL,portMAX_DELAY);
		hControl.AccData=!hControl.AccData;
		//printf("Choc \r\n");
		vTaskDelay(50);
	}
}

/* ============================= */
/*       TASK   TOFS          */
/* ============================= */
void taskTOFDetection(void *unused)
{
	printf("[TOF] Task Loop Start\r\n");

	// Le démarrage du timer ici est correct car TOF_Init est déjà fait
	if (HAL_TIM_Base_Start_IT(&htim17) != HAL_OK)
		printf("[TOF] Erreur Timer 17\r\n");
	for (;;)
	{
		// On attend le top du Timer 17 (20ms)
		if (xSemaphoreTake(sem_TimerTOF, portMAX_DELAY) != pdTRUE)
		{
			printf("[TOF] timeout sem_TimerTOF\r\n");
			continue;
		}

		int new_vide = 0;
		// Canal 0 : Gauche
		if (data_read_TOF(VL53L0X_DEFAULT_ADDRESS, 0) == 1) {
			new_vide |= 1;
		}
		// Canal 1 : Centre / Avant
		if (data_read_TOF(VL53L0X_DEFAULT_ADDRESS, 1) == 1) {
			new_vide |= 2;
		}
		// Canal 2 : Droite
		if (data_read_TOF(VL53L0X_DEFAULT_ADDRESS, 2) == 1) {
			new_vide |= 4;
		}
		// Canal 3 : Arrière (On ne le lit que si l'avant est "safe")
		if (data_read_TOF(VL53L0X_DEFAULT_ADDRESS, 3) == 1) {
			new_vide |= 8;
		}

		if (new_vide != 0) {
			hControl.vide = new_vide;
		}
		else {
			// On ne remet à zéro hControl.vide QUE si aucun capteur ne voit de vide
			hControl.vide = 0;
		}

		// --- DEBUG ---
		// if(new_vide != 0) printf("[TOF] Detection Vide sur Canal : %d\r\n", new_vide);
	}
}

/* ============================= */
/*       TASK  MOTOR et odométrie      */
/* ============================= */
void Task_Motor(void *argument)
{
	Odom_t odom_local;
	odom_local=hControl.odom;
	for(;;)
	{
		Encodeur_Read(&enc);//lecture encodeurs
		Odom_Update(&odom_local,&enc,&odom_params);//mise à jour odométrie
		hControl.odom=odom_local;
		//printf("Position : x=%f,y=%f, theta=%f degres \r\n",hControl.odom.x,hControl.odom.y, hControl.odom.theta * 180.0f / M_PI);
		Motor_UpdateSpeed(&hControl.hMotors);
		vTaskDelay(pdMS_TO_TICKS(10));
	}
}

/* ============================= */
/*       TASK  Control     */
/* ============================= */
void Task_Control(void *unused)
{
	printf("[CTRL] start\r\n");
	// --- INITIALISATION DES LEDS ---
	// Au démarrage, le robot est inactif (Rouge allumé, Vert éteint)
	HAL_GPIO_WritePin(GPIOA, GPIO_PIN_4, GPIO_PIN_SET);   // Rouge ON
	HAL_GPIO_WritePin(GPIOA, GPIO_PIN_5, GPIO_PIN_RESET); // Vert OFF
	// Vitesses augmentées
	const float V_FWD  = 0.18f;
	const float V_BACK = -0.14f;
	const float V_TURN = 0.14f;
	typedef enum { MOVE_FWD, MOVE_BRAKE, MOVE_BACKWARD, MOVE_TURN } state_t;
	state_t current_state = MOVE_FWD;
	int robot_active = 0;    // Le robot commence arrêté
	int last_acc_val = 0;    // Pour détecter le changement (front montant) sur AccData
	int timer_state = 0;
	int side_memory = 0;
	int last_turn_dir = 0;
	for (;;)
	{
		int vide;
		int current_acc;
		float vL = 0.0f;
		float vR = 0.0f;
		//lecture données
		vide = hControl.vide;
		current_acc = hControl.AccData; // Supposons que AccData passe à 1 lors d'un choc
		// --- LOGIQUE START/STOP (ACCÉLÉRO) ---
		if (current_acc == 1 && last_acc_val == 0) {
			robot_active = !robot_active;
			printf("[CTRL] ACC CHOC ! Robot %s\n", robot_active ? "START" : "STOP");

			if (robot_active) {
				// PASSAGE EN MARCHE : Vert ON, Rouge OFF
				HAL_GPIO_WritePin(GPIOA, GPIO_PIN_5, GPIO_PIN_SET);   // Vert
				HAL_GPIO_WritePin(GPIOA, GPIO_PIN_4, GPIO_PIN_RESET); // Rouge

				current_state = MOVE_FWD;
			} else {
				// PASSAGE EN ARRÊT : Rouge ON, Vert OFF
				HAL_GPIO_WritePin(GPIOA, GPIO_PIN_4, GPIO_PIN_SET);   // Rouge
				HAL_GPIO_WritePin(GPIOA, GPIO_PIN_5, GPIO_PIN_RESET); // Vert

				current_state = MOVE_BRAKE;
				timer_state = 1;
			}
		}
		last_acc_val = current_acc;
		// --- MACHINE À ÉTATS ---
		if (robot_active) {
			switch (current_state)
			{
			case MOVE_FWD:
				if ((vide & 1) || (vide & 2) || (vide & 4)) {
					side_memory = vide;
					current_state = MOVE_BRAKE;
					timer_state = 1; // Freinage immédiat
					printf("[CTRL] DANGER (%d) -> STOP\r\n", vide);
				} else {
					vL = V_FWD; vR = V_FWD;
				}
				break;
			case MOVE_BRAKE:
				// Envoie juste une commande de vitesse nulle.
				vL = -0.05f;
				vR = -0.05f;

				timer_state--;
				if (timer_state <= 0) {
					current_state = MOVE_BACKWARD;
					timer_state = 60;
					printf("[CTRL] Debut Recul 1.2s\r\n");
				}
				break;
			case MOVE_BACKWARD:
				if (vide & 8) { // Sécurité Arrière
					vL = 0.0f; vR = 0.0f;
					current_state = MOVE_TURN;
					printf("[CTRL] DANGER (%d) -> STOP\r\n", vide);
					timer_state = 30; // Rotation plus rapide
				} else {
					vL = V_BACK; vR = V_BACK;
					timer_state--;
					if (timer_state <= 0) {
						current_state = MOVE_TURN;
						timer_state = 35; // Environ 90° à 0.15f
					}
				}
				break;
			case MOVE_TURN:
				// Si vide détecté pendant rotation, on repart en arrière
				if (((vide & 1) || (vide & 2) || (vide & 4)) && ((vide & 8) == 0)) {
					current_state = MOVE_BRAKE;
					timer_state = 1;
					break;
				}

				if (side_memory & 1 || side_memory & 2) { // Gauche ou Centre -> Droite
					vL = V_TURN; vR = -V_TURN;
					last_turn_dir = 2;
				} else if (side_memory & 4) { // Droite -> Gauche
					vL = -V_TURN; vR = V_TURN;
					last_turn_dir = 1;
				} else {
					if (last_turn_dir == 1) { vL = -V_TURN; vR = V_TURN; }
					else { vL = V_TURN; vR = -V_TURN; }
				}

				timer_state--;
				if (timer_state <= 0) {
					current_state = MOVE_FWD;
					side_memory = 0;
				}
				break;
			}
		} else {
		    // Robot inactif : On coupe tout pour le silence et la batterie
		    vL = 0.0f; vR = 0.0f;
		    hControl.hMotors.mode_mot1 = STANDBY_MODE;
		    hControl.hMotors.mode_mot2 = STANDBY_MODE;
		    Motor_SetMode(&hControl.hMotors);
		}
		// --- ENVOI COMMANDES ---
		Motor_CommandVelLR(&hControl.hMotors, vL, vR);
		vTaskDelay(pdMS_TO_TICKS(20));
	}
}
/* USER CODE END 0 */

/**
 * @brief  The application entry point.
 * @retval int
 */
int main(void)
{

	/* MCU Configuration--------------------------------------------------------*/

	/* Reset of all peripherals, Initializes the Flash interface and the Systick. */
	HAL_Init();

	/* Configure the system clock */
	SystemClock_Config();

	/* Configure the peripherals common clocks */
	PeriphCommonClock_Config();

	/* Initialize all configured peripherals */
	MX_GPIO_Init();
	MX_TIM1_Init();
	MX_TIM2_Init();
	MX_I2C1_Init();
	MX_I2C3_Init();
	MX_LPTIM1_Init();
	MX_LPUART1_UART_Init();
	MX_USART1_UART_Init();
	MX_TIM17_Init();
	/* USER CODE BEGIN 2 */
	printf(" ------ FELIX READY ------\r\n ");
	/* ======================== INIT ========================= */
	/* 1. RESET LOGICIEL I2C (Pour débloquer le bus si gelé) */
	__HAL_I2C_DISABLE(&hi2c3);
	HAL_Delay(10);
	__HAL_I2C_ENABLE(&hi2c3);

	//initialisation lidar

	//intialisation TOFS
	if (TOF_Init() != 1) {
		printf("[TOF] FATAL ERROR: Panne materielle I2C\r\n");
		// On ne bloque pas tout le robot, mais on met un flag d'erreur
		hControl.vide = -1;
	} else {
		printf("[TOF] Initialisation reussie !\r\n");
	}

	//création sémaphores
	sem_TimerTOF = xSemaphoreCreateBinary();
	sem_ADXL = xSemaphoreCreateBinary();

	//Initialisation moteurs
	hControl.hMotors.m1_forward_channel = TIM_CHANNEL_1;
	hControl.hMotors.m1_reverse_channel = TIM_CHANNEL_2;
	hControl.hMotors.m2_forward_channel = TIM_CHANNEL_4; //J'ai échangé 3 et 4 pour que quand on veuille être en mode fwd, les deux roues sont dans le mm sens
	hControl.hMotors.m2_reverse_channel = TIM_CHANNEL_3;
	Motor_Init(&hControl.hMotors, &htim1);

	//initialisation variables tâches
	ControlData_Init();

	//initialisation accelero
	hControl.AccData=0;
	ADXL_Init(&adxl);
	ADXL_SetOffset(2,0,-63);
	ADXL_Measure(ON);

	//initialisation odométrie
	Encodeur_Init();
	Odom_Init(&hControl.odom);

	//initialisation asservissement (non testé)
	PID_Init(&pid_left,
			0.0f,     // Kp
			0.0f,     // Ki
			-100.0f,
			100.0f);

	PID_Init(&pid_right,
			0.0f,
			0.0f,
			-100.0f,
			100.0f);

	/* ======================== CREATION TACHES ========================== */
	if(xTaskCreate(taskTOFDetection,   "TOF",  1024, NULL, 2, NULL) != pdPASS){
		printf("Error creating task detection\r\n");
		Error_Handler();
	}
	if(xTaskCreate(taskAccelDetection, "ACC",   512, NULL, 1, NULL)!= pdPASS){
		printf("Error creating task accel\r\n");
		Error_Handler();
	}

	if(xTaskCreate(Task_Control, "CTRL", 1024, NULL, 3, NULL)!= pdPASS){
		printf("Error creating task ctrl\r\n");
		Error_Handler();
	}
	if(xTaskCreate(Task_Motor, "Task_Motor", 1024, NULL, 4, NULL)!= pdPASS){
		printf("Error creating task motor\r\n");
		Error_Handler();
	}


	vTaskStartScheduler();
	/* USER CODE END 2 */

	/* Call init function for freertos objects (in cmsis_os2.c) */
	MX_FREERTOS_Init();

	/* Start scheduler */
	osKernelStart();

	/* We should never get here as control is now taken by the scheduler */

	/* Infinite loop */
	/* USER CODE BEGIN WHILE */
	while (1)
	{
		/* USER CODE END WHILE */

		/* USER CODE BEGIN 3 */

	}
	/* USER CODE END 3 */
}

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
/**
 * @brief  Period elapsed callback in non blocking mode
 * @note   This function is called  when TIM16 interrupt took place, inside
 * HAL_TIM_IRQHandler(). It makes a direct call to HAL_IncTick() to increment
 * a global variable "uwTick" used as application time base.
 * @param  htim : TIM handle
 * @retval None
 */
void HAL_TIM_PeriodElapsedCallback(TIM_HandleTypeDef *htim)
{
	if (htim->Instance == TIM16)
	{
		HAL_IncTick();
	}
	/* USER CODE BEGIN Callback 1 */
	else if (htim->Instance == TIM17)
	{
		if (sem_TimerTOF != NULL)
		{
			BaseType_t hpw = pdFALSE;
			xSemaphoreGiveFromISR(sem_TimerTOF, &hpw);
			portYIELD_FROM_ISR(hpw);
		}
	}
	/* USER CODE END Callback 1 */
}

/**
 * @brief  This function is executed in case of error occurrence.
 * @retval None
 */
void Error_Handler(void)
{
	/* USER CODE BEGIN Error_Handler_Debug */
	/* User can add his own implementation to report the HAL error return state */
	__disable_irq();
	while (1)
	{
	}
	/* USER CODE END Error_Handler_Debug */
}
#ifdef USE_FULL_ASSERT
/**
 * @brief  Reports the name of the source file and the source line number
 *         where the assert_param error has occurred.
 * @param  file: pointer to the source file name
 * @param  line: assert_param error line source number
 * @retval None
 */
void assert_failed(uint8_t *file, uint32_t line)
{
	/* USER CODE BEGIN 6 */
	/* User can add his own implementation to report the file name and line number,
     ex: printf("Wrong parameters value: file %s on line %d\r\n", file, line) */
	/* USER CODE END 6 */
}
#endif /* USE_FULL_ASSERT */

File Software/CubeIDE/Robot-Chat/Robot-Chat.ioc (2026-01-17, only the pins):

Mcu.UserName=STM32WB55CEUx
PA0.GPIO_Label=Enc2A
PA0.Signal=S_TIM2_CH1
PA1.GPIO_Label=Enc2B
PA1.Signal=S_TIM2_CH2
PA10.GPIO_Label=M2_FWD
PA10.Signal=S_TIM1_CH3
PA11.GPIO_Label=M2_REV
PA11.Signal=S_TIM1_CH4
PA13.Signal=SYS_JTMS-SWDIO
PA14.Signal=SYS_JTCK-SWCLK
PA2.Signal=LPUART1_TX
PA3.Signal=LPUART1_RX
PA4.GPIO_Label=LED_ROUGE
PA4.Signal=GPIO_Output
PA5.GPIO_Label=LED_VERTE
PA5.Signal=GPIO_Output
PA7.Signal=I2C3_SCL
PA8.GPIO_Label=M1_FWD
PA8.Signal=S_TIM1_CH1
PA9.GPIO_Label=M1_REV
PA9.Signal=S_TIM1_CH2
PB0.Signal=GPXTI0
PB1.Signal=GPXTI1
PB3.Signal=SYS_JTDO-SWO
PB4.Signal=I2C3_SDA
PB5.Signal=LPTIM1_IN1
PB6.Signal=USART1_TX
PB7.Signal=LPTIM1_IN2
PB8.Signal=I2C1_SCL
PB9.Signal=I2C1_SDA

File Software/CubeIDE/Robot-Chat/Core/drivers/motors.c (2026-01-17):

/*
 * motors.c
 *
 *  Created on: Nov 17, 2025
 *      Author: mbeng
 */

#include "motors.h"
#include "tim.h"
#include <stdio.h>

// ---------------------------------------------------------------------------
/* INIT : Initialise la structure logicielle,
 * configure les rampes et démarre physiquement les quatre signaux PWM du timer pour les moteurs.
 */
// ---------------------------------------------------------------------------
void Motor_Init(h_Motor_t *hMotors, TIM_HandleTypeDef *htim)
{
	hMotors->htim_pwm = htim;



	hMotors->current_speed1 = 0.0f;
	hMotors->current_speed2 = 0.0f;
	hMotors->target_speed1  = 0.0f;
	hMotors->target_speed2  = 0.0f;

	hMotors->mode_mot1 = STANDBY_MODE;
	hMotors->mode_mot2 = STANDBY_MODE;
	// Ramp settings
	hMotors->speed_ramp1 = 1500;// 3200 / 1500 => ~2 itérations pour l'arrêt
	hMotors->speed_ramp2 = 1500;
	// Start PWM on ALL channels used
	HAL_TIM_PWM_Start(htim, hMotors->m1_forward_channel);
	HAL_TIM_PWM_Start(htim, hMotors->m1_reverse_channel);
	HAL_TIM_PWM_Start(htim, hMotors->m2_forward_channel);
	HAL_TIM_PWM_Start(htim, hMotors->m2_reverse_channel);

	Motor_SetMode(hMotors);
}

// ---------------------------------------------------------------------------
/* MOTOR MODE SWITCH :
 * Configure l'état des sorties PWM
 * (marche avant, arrière, freinage ou roue libre) pour chaque moteur en agissant sur le pont en H.
 */
// ---------------------------------------------------------------------------
void Motor_SetMode(h_Motor_t *hMotors)
{
	uint32_t ARR = hMotors->htim_pwm->Init.Period;

	// ----------------- MOT1 -------------------
	switch (hMotors->mode_mot1)
	{
	case FORWARD_MODE:
		__HAL_TIM_SET_COMPARE(hMotors->htim_pwm, hMotors->m1_reverse_channel, 0);
		break;

	case REVERSE_MODE:
		__HAL_TIM_SET_COMPARE(hMotors->htim_pwm, hMotors->m1_forward_channel, 0);
		break;

	case BRAKE_MODE:
		__HAL_TIM_SET_COMPARE(hMotors->htim_pwm, hMotors->m1_forward_channel, ARR);
		__HAL_TIM_SET_COMPARE(hMotors->htim_pwm, hMotors->m1_reverse_channel, ARR);
		break;

	default: // STANDBY
		__HAL_TIM_SET_COMPARE(hMotors->htim_pwm, hMotors->m1_forward_channel, 0);
		__HAL_TIM_SET_COMPARE(hMotors->htim_pwm, hMotors->m1_reverse_channel, 0);
		break;
	}

	// ----------------- MOT2 -------------------
	switch (hMotors->mode_mot2)
	{
	case FORWARD_MODE:
		__HAL_TIM_SET_COMPARE(hMotors->htim_pwm, hMotors->m2_reverse_channel, 0);
		break;

	case REVERSE_MODE:
		__HAL_TIM_SET_COMPARE(hMotors->htim_pwm, hMotors->m2_forward_channel, 0);
		break;

	case BRAKE_MODE:
		__HAL_TIM_SET_COMPARE(hMotors->htim_pwm, hMotors->m2_forward_channel, ARR);
		__HAL_TIM_SET_COMPARE(hMotors->htim_pwm, hMotors->m2_reverse_channel, ARR);
		break;

	default: // STANDBY
		__HAL_TIM_SET_COMPARE(hMotors->htim_pwm, hMotors->m2_forward_channel, 0);
		__HAL_TIM_SET_COMPARE(hMotors->htim_pwm, hMotors->m2_reverse_channel, 0);
		break;
	}
}

// ---------------------------------------------------------------------------
/*
 * Convertit une consigne de vitesse exprimée en pourcentage (0-100%)
 * en une valeur brute de registre pour le timer (ARR).
 */
void Motor_SetSpeed_percent(h_Motor_t *hMotors, float m1_percent, float m2_percent)
{
	uint16_t ARR = hMotors->htim_pwm->Init.Period;

	hMotors->target_speed1 = (ARR * (m1_percent / 100.0f));
	hMotors->target_speed2 = (ARR * (m2_percent / 100.0f));
}

// ---------------------------------------------------------------------------
/*
 * Calcule et applique une consigne de vitesse identique pour les deux roues à partir d'une valeur en m/s
 * en la limitant à la vitesse maximale autorisée.
 */
void Motor_SetSpeed(h_Motor_t *hMotors, float speed)
{
	if (speed >  ROBOT_V_MAX) speed =  ROBOT_V_MAX;
	if (speed < -ROBOT_V_MAX) speed = -ROBOT_V_MAX;

	// Conversion m/s -> duty%
	float speed_abs = fabsf(speed);
	float duty_percent = (speed_abs / ROBOT_V_MAX) * 100.0f;
	if (duty_percent > 100.0f) duty_percent = 100.0f;

	// On ne change PAS le mode ici (sinon inversion instantanée)
	// On stocke juste la consigne physique
	hMotors->target_vel_left  = speed;
	hMotors->target_vel_right = speed;

	// On met juste la PWM cible
	Motor_SetSpeed_percent(hMotors, duty_percent, duty_percent);
}

// ---------------------------------------------------------------------------
// Helpers for LR command
// ---------------------------------------------------------------------------
static inline float clampf(float x, float lo, float hi)
{
	if (x < lo) return lo;
	if (x > hi) return hi;
	return x;
}

static inline float vel_to_pwm_target(float v)
{
	float v_abs = fabsf(v);
	float duty = (v_abs / ROBOT_V_MAX) * 100.0f;
	if (duty > 100.0f) duty = 100.0f;
	return duty; // percent
}

static inline int pwm_near_zero(float pwm)
{
	return (pwm < 100.0f); // seuil à ajuster (counts PWM)
}

static inline float pwm_to_percent(h_Motor_t *m, float pwm)
{
	float ARR = (float)m->htim_pwm->Init.Period;
	if (ARR <= 0.0f) return 0.0f;
	return (pwm / ARR) * 100.0f;
}

/*
 * Gère indépendamment la direction et la vitesse des roues gauche et droite
 * tout en sécurisant les inversions de sens brutales.
 */
void Motor_CommandVelLR(h_Motor_t *m, float v_left, float v_right)
{
    v_left  = clampf(v_left,  -ROBOT_V_MAX, ROBOT_V_MAX);
    v_right = clampf(v_right, -ROBOT_V_MAX, ROBOT_V_MAX);
    // Déterminer les modes cibles
    // Utilisation de BRAKE_MODE si la vitesse demandée est exactement 0 pour un arrêt net
    MotorMode target_mode1 = (v_left > 0.01f)  ? FORWARD_MODE : (v_left < -0.01f) ? REVERSE_MODE : BRAKE_MODE;
    MotorMode target_mode2 = (v_right > 0.01f) ? FORWARD_MODE : (v_right < -0.01f) ? REVERSE_MODE : BRAKE_MODE;
    uint32_t ARR = m->htim_pwm->Init.Period;
    // --- MOTEUR 1 ---
    if (m->mode_mot1 != target_mode1) {
        m->target_speed1 = 0.0f;
        // On autorise le changement de sens beaucoup plus tôt (sous 20% de la vitesse max)
        if (m->current_speed1 < (ARR * 0.2f)) {
            m->mode_mot1 = target_mode1;
            Motor_SetMode(m);
        }
    } else {
        m->target_speed1 = (fabsf(v_left) / ROBOT_V_MAX) * ARR;
    }

    // --- MOTEUR 2 --- (Identique à M1)
    if (m->mode_mot2 != target_mode2) {
        m->target_speed2 = 0.0f;
        if (m->current_speed2 < (ARR * 0.2f)) {
            m->mode_mot2 = target_mode2;
            Motor_SetMode(m);
        }
    } else {
        m->target_speed2 = (fabsf(v_right) / ROBOT_V_MAX) * ARR;
    }
}
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

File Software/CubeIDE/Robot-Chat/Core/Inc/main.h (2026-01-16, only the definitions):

#define Enc2A_Pin GPIO_PIN_0
#define Enc2A_GPIO_Port GPIOA
#define Enc2B_Pin GPIO_PIN_1
#define Enc2B_GPIO_Port GPIOA
#define LED_ROUGE_Pin GPIO_PIN_4
#define LED_ROUGE_GPIO_Port GPIOA
#define LED_VERTE_Pin GPIO_PIN_5
#define LED_VERTE_GPIO_Port GPIOA
#define M1_FWD_Pin GPIO_PIN_8
#define M1_FWD_GPIO_Port GPIOA
#define M1_REV_Pin GPIO_PIN_9
#define M1_REV_GPIO_Port GPIOA
#define M2_FWD_Pin GPIO_PIN_10
#define M2_FWD_GPIO_Port GPIOA
#define M2_REV_Pin GPIO_PIN_11
#define M2_REV_GPIO_Port GPIOA

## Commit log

2025-09-18 PCB - Ajout schématique driver
    [Driver.kicad_sch]
2025-09-18 Update and rename Hardware/PCB_robot_chat.kicad_sch to Hardware/PCB_Florian/PCB_robot_chat.kicad_sch
    [PCB_robot_chat.kicad_sch]
2025-09-19 PCB - Updated Driver schematic
    [Driver.kicad_sch]
2025-10-01 Fixed error pins timers, PCB version 4
    [PCB_robot_chat.kicad_pcb, STM.kicad_sch]
2025-10-01 Created stm32CubeIDE project and initalized it
2025-10-01 PCB final version
    [PCB_robot_chat.kicad_pcb, STM.kicad_sch]
2025-10-01 Modified pin M_control for the Lidar, PCV version 7
    [PCB_robot_chat.kicad_pcb, STM.kicad_sch]
2025-11-14 added BOM
    [PCB_robot_chat_BOM.csv]
2025-11-14 Deleted antenna space btw signals and change R2 value
    [PCB_robot_chat.kicad_pcb, power.kicad_sch]
2025-11-19 Test motors ok
2025-11-26 Create Meca folder
    [Base - Parts - Support Motor.3mf, Base - Parts - Support Motor.stl, Base - Parts.3mf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]
2025-11-26 Created motors task
2025-12-02 Test 2 motors ok + tasks creation
2025-12-10 tests tâches moteurs et odometrie
2026-01-14 Meca update
    [Wheels Clean V2.stl, Wheels_Clean_V3.stl, Wheels_Clean_V4.stl]
2026-01-15 Version beta ok (sans lidar)
2026-01-15 ajout des user_labels
2026-01-16 Version 1 ok avec leds
2026-01-26 Add LIDAR sensor driver files

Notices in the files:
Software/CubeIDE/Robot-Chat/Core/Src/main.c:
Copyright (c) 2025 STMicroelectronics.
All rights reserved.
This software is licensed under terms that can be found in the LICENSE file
